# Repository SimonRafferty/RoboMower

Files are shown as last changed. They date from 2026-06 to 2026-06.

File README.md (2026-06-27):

# RoboMower - Autonomous RTK GPS Lawnmower
ESP32-S3 firmware for a home-built robot mower.  RTK GPS for positioning, VESC motor controllers over CANBUS, and a RadioMaster TX16S for manual driving & telemetry.

Why build one when you can buy a robot mower off the shelf?  The commercial ones either want a wire burying around the garden, or cost about the same as a small car - and none of them will cut a meadow.  This one is built like a small tank, cuts at whatever height you like and knows where it is to a couple of centimetres.
It's also an interesting project!

My intention with publishing this is so you can design your own mechanical hardware - any brushless drive and blade motors will work, controlled with VESCs. I'm using cheap knock-off 75100 types from AliExpress which seem to work great.

I'm going to publish the cad files for my mechanics but they might not be all that useful as the mower was mostly built out of bits I had laying around. you could do a much better job buying the 'right' parts.

in the settings (Web UI) I've tried to cover as many permutations of the layout of wheels, tracks etc as possible.

Watch the RoboMower mowing the lawn (https://www.youtube.com/watch?v=C5biq-wlkIc)

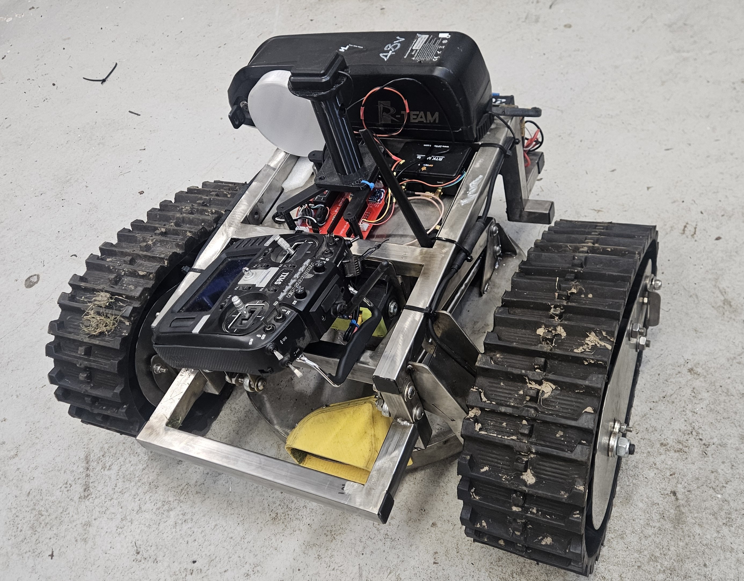
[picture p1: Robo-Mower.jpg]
The RoboMower - built like a small tank, because it basically is one


▶ I'm going to make a cover for the electronics which will make it look tidier! 

## How it works

You teach it the garden by driving it around the edge with the RC transmitter (or drawing the boundary on the map in the WebUI - both work).  That recorded line is the limit the mower's steering centre is allowed to reach, and it plans a path that covers everything inside it.

The path planning borrows the idea from a 3D printer slicer.  It follows the perimeter, then spirals inward ring by ring - each ring one cut-width inside the last - until it reaches the middle, so the whole lawn is covered in one continuous path.  If the garden pinches into separate areas (a neck through to a side lawn, say), each area gets its own spiral.

Position comes from a DFRobot RTK GPS (which was the most reasonably priced I could find).  The mower only trusts the GPS when it has a centimetre-accurate **RTK-Fixed** solution; the rest of the time it dead-reckons on wheel odometry.  That matters because gardens have trees, and RTK drops to a less accurate "Float" solution (sometimes a metre or two out) under the canopy - so rather than chase a bad fix, it coasts on odometry until a clean Fixed comes back.  Heading comes from a magnetometer-based 9-axis IMU (a Bosch BNO055): its on-chip fusion gives a tilt-compensated absolute compass heading, with a small offset trimmed from the GPS travel direction on straight RTK-Fixed runs.  The wheel-odometry scale (ticks per metre) and track width are self-calibrated against the GPS, again only on Fixed.

In case you're interested, you can find small tracks on eBay & AliExpress, intended for ATV's.  I used a pair of Bafung geared e-bike front wheel motors with the freewheel clutch welded up so they will drive in reverse to drive the tracks.  They produce bags of torque at low current and are super robust!

If it gets stuck in long wet grass, it raises the cutting deck, has another go, and progressively lowers it again.  If the blade is working too hard, it finishes the strip at maximum height and re-traces lower.  If it hits something (detected by the IMU - no bumpers), it notes the position as an obstacle and routes around it next time.

## Hardware

* ESP32-S3 DevKitC-1, the **N16R8** version (16MB Flash / 8MB PSRAM).  Be careful here - if you flash this firmware onto a generic S3 board with different memory, you'll likely brick it and need the Espressif Flash Download Tool or JTAG to recover it.  Ask me how I know.
* DFRobot GNSS-RTK board (Quectel LC29H) + NTRIP corrections.  Gives 1-2cm accuracy when it has an RTK Fixed solution.
* Bosch BNO055 9-axis IMU - on-chip sensor fusion gives an absolute heading; also used for tilt safety and collision detection.
* 3x VESC motor controllers on CANBUS at 250 kbit/s.  Mine are a mixed bag: two older HW4.x for the wheels (ID 1 & 2) and a HW6 for the blade (ID 3).  The older ones work fine, but make sure "Send CAN Status" is enabled in VESC Tool on ALL of them - the firmware needs the eRPM feedback, and the old boards default to silent.
* Blade motor is from a Gtech cordless mower (CLM021) - cheap, light and surprisingly tough.  The VESC limits it to 2800 RPM, so the firmware just asks for full speed and lets the VESC's current limit do the soft start.
* 13S battery, RadioMaster TX16S + ER8 receiver (ELRS), a linear actuator for cut height, and a PILZ safety relay as a proper hardware E-stop in the 48V line.  The ESP32 runs on a supercap backup so it doesn't lose its position when the PILZ fires or you swap the battery.

## Controls & monitoring

Day to day you don't need a laptop for anything.  The TX16S runs a Lua widget (in the repository) showing state, battery, blade load, GPS quality and a compass (with a line pointing at the next waypoint) - and it beeps at you when the mower wants attention.  CH4 selects Manual / Auto / Nudge, CH5 records the perimeter, CH6 arms the blade, CH7 pauses.

A few things make it pleasant to live with.  **Nudge** (CH4 up) hands the sticks back to you mid-mow without ending the run - shove it off an obstacle or correct a drift, flick back to Auto and it carries on exactly where it was.  Pausing and flicking back to Auto does the same as long as the mower hasn't been moved; if you carried it somewhere, it starts the cycle again.  And rather than swing a wide arc to reach a point behind it (which could wander over the boundary), it simply reverses to it.

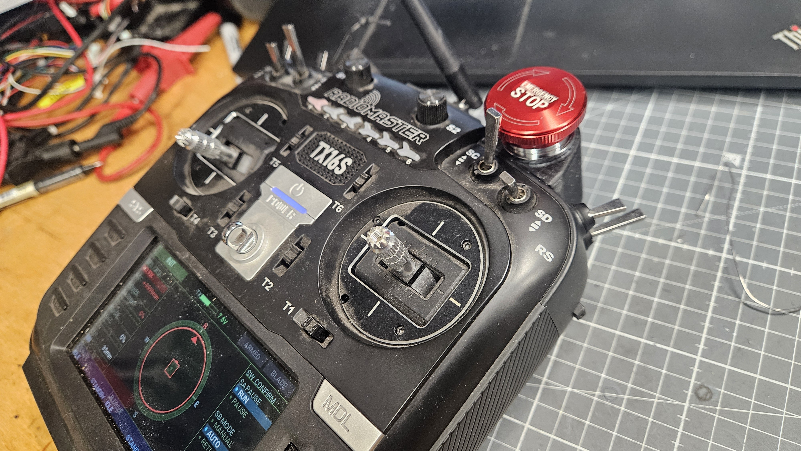
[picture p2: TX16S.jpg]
The TX16S running the Lua telemetry widget


*Everything at a glance on the transmitter - state, compass, GPS quality and blade load.  The big red button is exactly what it looks like.*

There's also a WebUI - a single HTML file that connects over Bluetooth from a phone (Chrome on Android).  That gives you a live map, perimeter editing, config settings and a diagnostics page with the raw VESC data.  If something misbehaves, the System Log on the dashboard tells you what the mower decided and why - copy & paste it if you want help.

When the battery gets low it warns you on the transmitter and the phone, then leaves the decision to you.  The VESCs look after themselves as the voltage drops, so there's no need for the firmware to panic on your behalf.

# Important Note:
If you use a different VESC for the blade, check which bytes of the CAN STATUS_5 message you're reading.  I had a bug where the firmware read the first two bytes (which are actually the tachometer) as the battery voltage.  It decoded as -0.1V, the firmware decided the battery was flat, and quietly refused to start the blade - while the transmitter cheerfully displayed "Armed & Running".  That one took a while to find.  The voltage is in bytes 4-5.
#

## Libraries & Dependencies

Built and tested against the versions below (the libraries are the **exact** versions used).  The firmware compiles on the **esp32 board core from 3.0.5 through the current 3.3.x** — newer cores moved the ESP32-S3 onto the NimBLE Bluetooth stack, and the code now handles both backends, so you don't need to pin an old core any more.  Install the core in **Boards Manager** and the libraries in **Library Manager** (Arduino IDE):

| Dependency | Version | What it's for |
|---|---|---|
| Arduino IDE | 2.x | (or arduino-cli 1.5.x) |
| **esp32** by Espressif (board core) | **3.0.5 – 3.3.x** | ESP32-S3 board support — and BLE, `Wire`, `Preferences`/NVS, LEDC (servo), TWAI (CAN) and FreeRTOS all ship with it.  Anything from 3.0.5 to the current 3.3.x builds; 3.0.5 is the most field-tested if you want to play it safe. |
| Adafruit BNO055 | 1.6.4 | the IMU |
| Adafruit Unified Sensor | 1.1.15 | dependency of the BNO055 library |
| Adafruit BusIO | 1.17.4 | dependency of the Adafruit libraries (Library Manager installs it for you) |
| FastLED | 3.10.3 | the status LED strip |
| DFRobot_RTK_LoRa | 1.0.0 | the RTK GPS board |

**Clipper2** (polygon offsetting for the spiral path planner) is **bundled in the repo** at `Robo-Mower-V2/src/clipper2/` — Arduino compiles the sketch's `src/` folder automatically, so there's nothing to install.

> **Getting `'esp_ble_gatts_cb_param_t' has not been declared`?**  That was an older version of this firmware, which only built on core 3.0.x.  **Pull the latest commit** — it now builds on 3.0.5 through the current 3.3.x.  (If you're stuck on an old firmware copy for some reason, installing **esp32 3.0.5** in Boards Manager and selecting it for this build also works.)

## Setting it up

1. Install the core + libraries from **Libraries & Dependencies** above.  Board "ESP32S3 Dev Module", Partition Scheme "Huge APP (3MB No OTA)", PSRAM "OPI PSRAM".
2. In VESC Tool: set CAN IDs 1 (left), 2 (right), 3 (blade), baud 250 kbit/s, enable CAN status messages on all three.  Drive motors in current control, blade in speed control with a 2800 RPM limit.
3. Wiring, calibration and the full operating procedure are in manual.md.  The CRSF telemetry format (if you want to build your own display) is in telemetry.md.
4. Drive the perimeter, press Auto, and watch it go.

Thanks to Benjamin Vedder for the VESC project - which makes projects like this possible, and to the OpenMower project for convincing me RTK GPS was the right approach.

I did consider just building the OpenMower project - but it's intended for a specific off the shelf mower rather than something mostly home built.  It would have taken extensive re-writing, so I decided to go it alone.  I also preferred to use an ESP32 rather than an RPi just because it boots near instantly.  I wasn't sure the whole thing would fit in an ESP32, but here it is!

Feel free to copy, share, change - whatever you like!

NOTE:
This is a DIY, experimental project.  It is not a turn-key product, and getting something wrong can put a heavy machine with a spinning blade somewhere you don't want it!  If you are not confident with electronics, software and/or mechanics - please walk away unless you're not fond of your fingers & toes!!!

I do not accept responsibility if it mows your flower beds, your neighbour's fence, the cat - or you!

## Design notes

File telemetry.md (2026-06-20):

# CRSF Telemetry Reference

ESP32-S3 → ER8 receiver → RadioMaster TX16S

## Overview

Five CRSF frame types are transmitted in a fixed rotation, one frame per
inter-packet gap (~2 ms silence between incoming RC frames at 100 Hz).
Data is snapshot at **2 Hz** by the state machine; frames are dispatched by
the CRSF receive task whenever a gap is detected.

**Rotation order:** FLIGHT_MODE → GPS → BATTERY → MOWER_STATUS → ATTITUDE → repeat

**Baud rate:** 420 000 (standard CRSF)

**Serial:** `Serial2` (ESP32-S3 UART2)

---

## Frame Format (all frames)

```
[sync] [len] [type] [payload ...] [CRC8]
```

| Byte | Description |
|---|---|
| `0xC8` | Sync byte (CRSF standard) |
| `len`  | `payload_len + 2` (counts type + CRC, excludes sync & len) |
| `type` | Frame type identifier |
| payload | Type-specific, see below |
| CRC8 | Polynomial `0xD5` (DVB-S2), computed over `type + payload` only |

---

## 1. FLIGHT_MODE — `0x1E`

Null-terminated ASCII string. Max 16 bytes (15 printable chars + `\0`).

**Payload (variable length, 2–16 bytes):**

| Offset | Type | Description |
|---|---|---|
| 0..N-1 | char[] | ASCII state name |
| N | `\0` | Null terminator (always present) |

**Possible values:**
`INIT`, `IDLE`, `MANUAL`, `LEARN`, `AUTO`, `RETRACE`, `BOG`, `OBS-AVOID`, `RETURN`, `PAUSED`, `MOT-OFF`

EdgeTX displays this natively on the main screen.

---

## 2. GPS — `0x02`

**Payload: 15 bytes, big-endian**

| Offset | Type | Unit | Description |
|---|---|---|---|
| 0–3 | int32 | degrees × 10⁷ | Latitude (WGS-84, EKF-fused) |
| 4–7 | int32 | degrees × 10⁷ | Longitude (WGS-84, EKF-fused) |
| 8–9 | uint16 | km/h × 100 | Ground speed (from EKF velocity × 3.6) |
| 10–11 | uint16 | degrees × 100 | Heading [0, 36000) |
| 12–13 | uint16 | metres + 1000 | Altitude (offset to stay unsigned; 0 m → 1000) |
| 14 | uint8 | count | Satellites used |

**Decoding in Lua:**
```lua
lat = payload_i32(0) / 1e7
lon = payload_i32(4) / 1e7
speed_kmh = payload_u16(8) / 100
heading_deg = payload_u16(10) / 100
alt_m = payload_u16(12) - 1000
sats = payload[14]
```

EdgeTX recognises this frame natively (GPS sensor).

---

## 3. BATTERY — `0x08`

**Payload: 8 bytes, big-endian**

| Offset | Type | Unit | Description |
|---|---|---|---|
| 0–1 | uint16 | V × 100 (centi-volts) | Battery voltage |
| 2–3 | uint16 | A × 100 (centi-amps) | Blade motor current |
| 4–6 | uint24 | mAh | Capacity used (3 bytes, MSB first) |
| 7 | uint8 | % | Battery remaining (0–100) |

**Battery:** 13S LiPo — full ≈ 54.6 V, low = 42.9 V (`BATTERY_LOW_V` in config.h)

**Decoding in Lua:**
```lua
voltage = payload_u16(0) / 100       -- volts
current = payload_u16(2) / 100       -- amps
cap_mah = (payload[4] << 16) | (payload[5] << 8) | payload[6]
remaining = payload[7]               -- percent
```

EdgeTX recognises this frame natively (battery sensor).

---

## 4. MOWER_STATUS — `0x80` (custom)

**Not an EdgeTX-standard frame.** Must be parsed by a Lua widget via
`crossfireTelemetryPop()`. Standard CRSF frame types (GPS, Battery, Attitude,
FlightMode) are consumed by EdgeTX internally and are **not** passed to Lua —
all data needed by the widget must be in this frame.

**Payload: 23 bytes** (15 before 2026-06-10, 19/20 before 2026-06-19, 22 before the beep-seq byte; the Lua widget accepts all — it length-guards each field)

| Offset | Type | Unit | Description |
|---|---|---|---|
| 0 | uint8 | enum | Robot state (see below) |
| 1 | uint8 | % | Headland progress (0–100) |
| 2 | uint8 | % | Strip progress (0–100) |
| 3 | uint8 | mm | Cut height |
| 4 | uint8 | % | Blade load (0–100) |
| 5 | uint8 | enum | GPS fix type (see below) |
| 6 | uint8 | bitfield | Status flags (see below) |
| 7–8 | uint16 | count | Obstacles detected (big-endian) |
| 9–10 | uint16 | cm | EKF position uncertainty (big-endian) |
| 11–14 | uint32 | dm² | Session mowed area (big-endian) |
| 15–16 | uint16 | V×100 | Battery voltage (big-endian) — duplicated here so the widget does not depend on the EdgeTX `RxBt` sensor |
| 17–18 | uint16 | deg×10 | Heading 0–359.9° (big-endian) — duplicated here so the widget does not depend on the EdgeTX `Yaw` sensor |
| 19 | uint8 | bitfield | BNO055 calibration: bits 7:6 sys, 5:4 gyro, 3:2 accel, 1:0 mag (each 0–3) |
| 20 | uint8 | enum | AUTO-start gate reason (0=OK/not gated; Lua banners it ~2 s) — see below |
| 21 | uint8 | deg/2 | Next-waypoint bearing, 0–179 = 0–358° (0=N, CW+), **255 = no waypoint**. Lua draws a yellow compass line |
| 22 | uint8 | counter | Beep sequence — incremented per `request_beep()`. Carried in every frame (not one-shot); the Lua plays the tone (type in flags bits 7:6) when this value advances, so a dropped frame can't lose a beep |

**AUTO-start gate reason (offset 20):**

| Value | Meaning |
|---|---|
| 0 | Not gated / OK |
| 1 | No perimeter taught |
| 2 | No GPS position (EKF unseeded) |
| 3 | Heading not GPS-established (drive a straight run) |
| 4 | GPS fix not RTK (need Float/Fixed) |
| 5 | EPE / Uncertainty too high |
| 6 | Mower outside perimeter |

**State values (offset 0):**

| Value | Name | Description |
|---|---|---|
| 0 | INIT | Boot / hardware init |
| 1 | IDLE | Armed, awaiting command |
| 2 | MANUAL | RC driving |
| 3 | LEARN | Recording perimeter |
| 4 | AUTO | Autonomous mowing |
| 5 | RETRACE | Overload recovery |
| 6 | BOG | Stall recovery |
| 7 | OBS-AVOID | Obstacle avoidance |
| 8 | NUDGE | AUTO held; operator drives via TX, then resumes |
| 9 | PAUSED | Mowing paused |
| 10 | MOT-OFF | Motors offline |

**Fix type values (offset 5):**

| Value | Meaning |
|---|---|
| 0 | No fix |
| 1 | GPS (autonomous) |
| 2 | DGPS |
| 4 | RTK fixed |
| 5 | RTK float |

**Flags bitfield (offset 6):**

| Bit | Meaning |
|-----|---|
| 0 | Armed |
| 1 | Blade on |
| 2 | Bog recovery active |
| 3 | Retrace active |
| 4 | RTK float (degraded) |
| 5 | Battery WARNING/LOW — Lua shows flashing battery banner (was "obstacle near", never implemented) |
| 7:6 | Beep request (2-bit field, see below) |

**Beep request (flags bits 7:6) — beep TYPE, carried in every frame (no longer one-shot):**

| Bits 7:6 | Value | Meaning |
|---|---|---|
| `00` | 0 | No beep |
| `01` | 1 | Confirm (short tone) |
| `10` | 2 | Warning (attention) |
| `11` | 3 | Fault (critical) |

The type alone is **not** an edge — pair it with the **beep sequence counter (byte 22)**. `request_beep()` bumps byte 22 per event; the Lua plays the tone of bits 7:6 only when byte 22 changes. This survives dropped frames (the next frame still carries the new sequence) and is handled in the widget's `background()` path so it beeps even when the widget isn't the focused screen — essential for per-corner LEARN confirmation.

**Decoding in Lua:**
```lua
local state_names = {
    [0]="INIT", [1]="IDLE", [2]="MANUAL", [3]="LEARN", [4]="AUTO",
    [5]="RETRACE", [6]="BOG", [7]="OBS-AVOID", [8]="RETURN",
    [9]="PAUSED", [10]="MOT-OFF"
}

state       = payload[0]
state_name  = state_names[state] or "?"
hprog       = payload[1]
sprog       = payload[2]
cut_mm      = payload[3]
blade_load  = payload[4]   -- 0–100 %; RPM-based since 2026-06-16 (Feature 2): 0 % at/above target rpm, 100 % at standstill
fix         = payload[5]
flags       = payload[6]
obs_count   = (payload[7] << 8) | payload[8]
ekf_unc_cm  = (payload[9] << 8) | payload[10]
mowed_dm2   = (payload[11] << 24) | (payload[12] << 16) | (payload[13] << 8) | payload[14]
mowed_m2    = mowed_dm2 / 100    -- convert dm² to m²

armed       = bit32.band(flags, 0x01) ~= 0
blade_on    = bit32.band(flags, 0x02) ~= 0
bog         = bit32.band(flags, 0x04) ~= 0
retrace     = bit32.band(flags, 0x08) ~= 0
rtk_float   = bit32.band(flags, 0x10) ~= 0
obs_near    = bit32.band(flags, 0x20) ~= 0
beep        = bit32.rshift(bit32.band(flags, 0xC0), 6)  -- 0=none 1=confirm 2=warn 3=fault
```

---

## 5. ATTITUDE — `0x14`

**Payload: 6 bytes, big-endian, signed**

| Offset | Type | Unit | Description |
|---|---|---|---|
| 0–1 | int16 | radians × 10000 | Pitch (always 0 — mower is flat) |
| 2–3 | int16 | radians × 10000 | Roll (always 0 — mower is flat) |
| 4–5 | int16 | radians × 10000 | Yaw (EKF heading, −π to +π) |

**Decoding in Lua:**
```lua
pitch_rad = payload_i16(0) / 10000
roll_rad  = payload_i16(2) / 10000
yaw_rad   = payload_i16(4) / 10000
heading_deg = math.deg(yaw_rad)    -- convert to degrees if needed
```

EdgeTX recognises this frame natively.

---

## CRC8 Implementation

Polynomial `0xD5` (DVB-S2). Input: `type` byte + all payload bytes. Sync and length bytes are excluded.

```lua
function crsf_crc8(data)
    local crc = 0
    for i = 1, #data do
        crc = bit32.bxor(crc, data:byte(i))
        for _ = 1, 8 do
            if bit32.band(crc, 0x80) ~= 0 then
                crc = bit32.bxor(bit32.lshift(crc, 1), 0xD5)
            else
                crc = bit32.lshift(crc, 1)
            end
            crc = bit32.band(crc, 0xFF)
        end
    end
    return crc
end
```

---

## Timing

- Data snapshot: updated at **2 Hz** (every 500 ms) from state machine
- Frame dispatch: one frame per CRSF inter-packet gap (~100 Hz opportunity)
- Rotation of 5 frames → each type sent ~20 times/sec (far exceeds 2 Hz data rate)
- Longest frame (GPS, 19 bytes total) takes ~360 µs at 420 kbaud — fits within the ~8 ms gap

---

## Source Files

| File | Purpose |
|---|---|
| `crsf_telemetry.h` | TelemetryData struct, public API |
| `crsf_telemetry.cpp` | Frame builders, CRC, rotation logic |
| `crsf_input.cpp` | CRSF receive + telemetry window detection |
| `state_machine.cpp` | Populates TelemetryData at 2 Hz |
| `config.h` | Battery voltage thresholds |

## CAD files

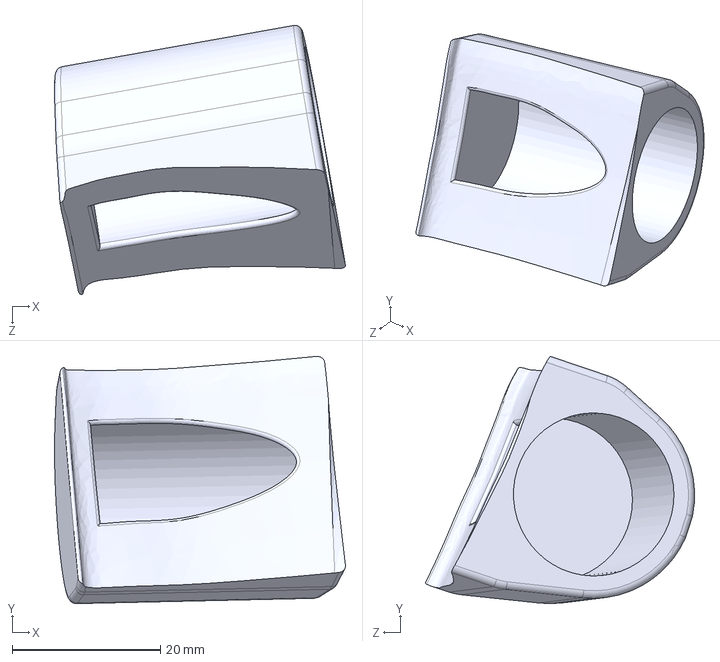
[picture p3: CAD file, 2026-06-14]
E-Stop Tx.STEP
39.3 x 33.4 x 36.3 mm

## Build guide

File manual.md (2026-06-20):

# RoboMower — User Manual

## Contents

1. [System Overview](#1-system-overview)
2. [RC Transmitter Layout](#2-rc-transmitter-layout)
3. [WebUI (Phone App)](#3-webui-phone-app)
4. [First Boot Checklist](#4-first-boot-checklist)
5. [Teaching the Perimeter](#5-teaching-the-perimeter)
6. [Starting a Mow](#6-starting-a-mow)
7. [Manual Driving](#7-manual-driving)
8. [Pause and Resume](#8-pause-and-resume)
9. [Emergency Stop](#9-emergency-stop)
10. [Cut Height](#10-cut-height)
11. [Battery](#11-battery)
12. [LED Status Reference](#12-led-status-reference)
13. [Configuration (WebUI)](#13-configuration-webui)
14. [Serial Debug Commands](#14-serial-debug-commands)
15. [Troubleshooting](#15-troubleshooting)

---

## 1. System Overview

RoboMower is a fully autonomous lawnmower controlled by an ESP32-S3 with RTK GPS positioning. It can be operated using a RadioMaster TX16S radio transmitter or a phone via Bluetooth (BLE).

**Key rule: RC transmitter and WebUI are mutually exclusive.** When the transmitter is switched on, the WebUI drive controls are locked out. Switch the transmitter off to use the phone.

**Hardware summary**

| Component | Role |
|---|---|
| ESP32-S3 DevKitC-1 (N16R8) | Main controller |
| Quectel LC29H + NTRIP | RTK GPS positioning (~5–10 cm accuracy) |
| RadioMaster TX16S + ER8 | RC control and telemetry |
| 3× VESCs (IDs 1, 2, 3) | Left drive, right drive, blade motor |
| PILZ safety relay | Hardware E-stop (cuts 48V bus) |
| 48V LiPo battery | Main power |
| Supercapacitor backup | Keeps ESP32 running for minutes after PILZ fires |

---

## 2. RC Transmitter Layout

All controls assume a RadioMaster TX16S in Mode 2 (throttle on the left stick). Assign switches as below — the exact physical switch is your choice as long as the channel numbers match.

| RC Channel | Function | Switch type | Position mapping |
|---|---|---|---|
| **CH1** | Steering | Left stick L/R | Left = turn left, Right = turn right |
| **CH2** | Throttle | Right stick U/D | Up = forward, Down = reverse |
| **CH3** | Cut height | Knob or slider | Low = minimum height, High = maximum height |
| **CH4** | Mode | 3-position switch | **Down** = MANUAL · **Centre** = AUTO · **Up** = NUDGE (hand sticks back, AUTO held) |
| **CH5** | Learn (perimeter record) | 2-position switch | Up (active) = recording on, Down = off |
| **CH6** | Arm (blade enable) | 2-position switch | Up = ARMED (blade allowed), Down = DISARMED |
| **CH7** | Pause / Soft E-stop | Momentary or latching button | Press/hold = pause all motion |
| **CH8** | Store point | Momentary button | One press = record current GPS position as a perimeter waypoint |

### CH4 Mode switch in detail

| CH4 position | State machine mode | What happens |
|---|---|---|
| Down | MANUAL | Operator drives with sticks; blade runs if CH6 armed |
| Centre | AUTO | Autonomous mowing (requires valid perimeter + GPS-established heading) |
| Up | NUDGE | AUTO is **held** — you drive the tracks with the sticks to nudge the mower (off an obstacle, or to correct a drift) **without ending the run**. Flip back to Centre and it resumes the mow exactly where it left off. The blade still follows CH6. (This replaced the old "return to start", which wasn't used.) |

> **Accidental mode switch:** if you flick AUTO → MANUAL by mistake and put it back to AUTO within ~4 seconds, it resumes the cycle where it left off rather than starting over. After 4 s, MANUAL → AUTO is treated as a fresh start.

### Telemetry on the TX16S

The mower transmits five CRSF telemetry frames back to the transmitter:
- **Flight mode** — shows current state name (INIT, IDLE, MANUAL, AUTO, etc.)
- **GPS** — position and speed (visible on EdgeTX GPS screen)
- **Battery** — voltage and estimated remaining %
- **Attitude** — heading
- **Mower Status (0x80)** — custom frame with mowing progress, blade load, fix quality, AUTO-deny reason, next-waypoint bearing, area mowed. Read with a Lua widget.

---

## 3. WebUI (Phone App)

The WebUI is a single HTML file (`robomower-pwa/robomower.html`). Open it in **Chrome on Android** — other browsers do not support Web Bluetooth.

> The phone controls only activate when the RC transmitter is **switched off** (failsafe active). A yellow banner at the top of the Controls tab says "RC Transmitter Active" and locks the buttons when the transmitter is on.

### Connecting

1. Open `robomower.html` in Chrome on Android.
2. Make sure the mower is powered on and the LED is showing a stable pattern (not INIT flashing).
3. Tap **Connect** in the top-right corner.
4. Select **RoboMower** from the Bluetooth device list.
5. The dot next to the Connect button turns green and shows **Connected**.

### Tabs

| Tab | Purpose |
|-----|---|
| **Dashboard** | Live status cards: state, GPS fix, battery, blade load, position uncertainty, session area. Also the Configuration panel (collapsed by default). |
| **Map** | Leaflet map showing the perimeter, planned mowing strips, GPS position, and coverage progress. Load/save/edit perimeter here. |
| **Controls** | All operational buttons: mode, arm, learn, drive sliders, cut height. |
| **Diagnostics** | Detailed real-time data from all sensors and subsystems. Only polls while the tab is open. |

### Controls tab — buttons

| Button | Function | Notes |
|---|---|---|
| **Manual** | Switch to MANUAL state | RC must be off |
| **Auto** | Switch to AUTO_MOWING state | Requires valid perimeter + GPS-established heading; mower must be inside it |
| **Learn** | Toggle perimeter learning on/off | See §5 |
| **Store Pt** | Record current GPS position as a waypoint | Only active during Learn mode |
| **Start Blade / Stop Blade** | Toggle blade arm | RC must be off. Only works in MANUAL or IDLE |
| **Pause / Resume** | Toggle BLE pause | Equivalent to pressing the CH7 button |

### Drive sliders

Two sliders replace the RC sticks when the transmitter is off:

- **Forward/Reverse slider** (left) — push up for forward, down for reverse. Returns to zero when released.
- **Left/Right slider** (right) — steer left or right. Returns to zero when released.

Sliders send commands continuously while held. The mower coasts to a stop within 2 seconds if the connection drops.

### Map tab — perimeter tools

| Button | Function |
|---|---|
| **Load from Mower** | Download the perimeter currently stored on the mower |
| **Send to Mower** | Upload the perimeter shown on the map to the mower |
| **Load File** | Load a perimeter JSON file from your phone |
| **Save File** | Save the current map perimeter as a JSON file |
| **Centre on GPS** | Pan the map to the mower's last known position |
| **Satellite** | Toggle between street map and satellite imagery |

You can draw and edit the perimeter directly on the map using the leaflet-geoman draw tools (pencil icon on the map). After editing, tap **Send to Mower** to upload it. Only the perimeter points are editable — the cut path and the GPS accuracy circles are display-only.

The map shows **two arrows**: a **red** one for the mower's fused (EKF) position and heading, and a **black** one for the raw GPS/RTK position and travel heading. When the fix is good they sit on top of each other; if the black one wanders off, that's the raw GPS being noisy (e.g. RTK "Float" under trees) and the red one is holding position on odometry — which is the intended behaviour. Each recorded perimeter corner also carries a small confidence circle sized to the GPS accuracy when it was taught.

---

## 4. First Boot Checklist

### Before power-on

- [ ] VESCs configured: CAN IDs set (Left=1, Right=2, Blade=3), baud 500 kbit/s, status broadcasts enabled. See README §6.
- [ ] NTRIP client running on a nearby device and corrections reaching the LC29H.
- [ ] 48V battery connected. PILZ relay in RUN state (green light).
- [ ] RC transmitter on, CH4 = MANUAL, CH6 = DISARMED, CH7 = not pressed.

### Power-on sequence

1. **Power on the ESP32** (supercapacitor supply or direct 5V).
2. The LED pulses **blue** slowly — this is the **INIT** state.
3. **Place the mower on flat ground and hold it completely still** for ~3 seconds while the gyro bias is collected. The LED shows blue throughout.
4. The mower waits for:
   - A valid RC signal (ER8 receiver linked to TX16S), AND
   - A GPS ENU origin (either loaded from NVS from a previous session, or the GPS must acquire a fix)
5. Once both are ready the LED changes to a slow **blue single blink** = **IDLE**.
6. On first use there is no stored origin. The GPS will auto-seed from the first RTK-quality fix. This may take 1–5 minutes if the NTRIP is slow to provide corrections.

---

## 5. Teaching the Perimeter

The perimeter defines the outermost boundary of the garden — the blade edge should follow this line exactly. Navigate the **blade edge** (not the chassis edge, not the antenna) along the desired outer cut line.

There are three ways to define the perimeter:

### Method A — Drive with RC (recommended for first setup)

1. CH4 = **MANUAL**, CH6 = **DISARMED**.
2. Flip **CH5** to active. The LED changes to fast green/amber flash = **LEARN**.
3. Drive slowly around the garden boundary. Points are recorded every 0.2 m of travel.
   - **Green fast flash** = RTK fixed (best accuracy ~2 cm)
   - **Amber fast flash** = RTK float (still good, ~5–15 cm)
4. When you return within 3 m of the start point the polygon closes automatically.
5. Flip **CH5** off to save. The LED flashes **white 3×** to confirm success, then returns to IDLE.

If the save fails (too few points, self-intersection, polygon too small), the LED returns to its previous pattern without the white flash. Check the serial output for the reason.

### Method B — Store individual points with RC + CH8

For precise corners or when driving continuously is difficult:

1. Enter LEARN mode as above (CH5 active).
2. Position the mower at each corner, then press the **CH8** momentary button to store that point. **The transmitter beeps once for each point recorded** — wait for the beep before moving on, so you don't double-record or miss a corner. Corners can be as little as 0.1 m apart.
3. When finished, flip CH5 off to close and save.

Each corner is tagged with the GPS accuracy at the moment you pressed CH8, so it's worth getting an **RTK-Fixed** solution (green LED) at each corner. A corner taught under tree cover in "Float" is automatically pulled slightly inward (toward the garden centre, by its uncertainty) so the mower keeps clear of the boundary there — the rest of the perimeter is unaffected.

### Method C — Draw on the WebUI map

1. Open the WebUI Map tab.
2. Use the draw tools to trace the perimeter directly on the satellite image.
3. Tap **Send to Mower** to upload. The mower derives the nav boundary and working area automatically.

You can also combine methods: record a rough perimeter by driving, tap **Load from Mower** in the WebUI, edit individual waypoints on the map to fix inaccurate sections, then **Send to Mower** again.

### After saving

The firmware automatically computes the **mowing plan**: a concentric inward spiral that follows the perimeter, then steps inward one cut-width per ring to the centre. If the garden pinches into separate areas, each is spiralled in turn. (A navigation boundary and working area are also derived and shown, but the spiral and the safety boundary work directly from the perimeter.)

The WebUI map shows the perimeter and the planned path after a successful upload or load.

---

## 6. Starting a Mow

### Via RC

1. Mower in **IDLE** state (blue single blink).
2. **Establish heading first.** The mower starts up with no absolute heading — it learns it from the GPS travel direction. Get an **RTK-Fixed** solution (green LED) and drive a short straight run in MANUAL; the TX compass swings to true North and then stays locked (you won't need to do it again unless you reset). AUTO will refuse to start until the heading is established (the TX banners the reason).
3. Set **CH4 = AUTO**.
4. Set **CH6 = ARMED** (blade on).
5. The mower enters AUTO_MOWING: LED = **orange double blink**.

The plan follows the perimeter, then spirals inward to the centre. If part of the garden is under tree cover and the fix drops to "Float", the mower keeps going on dead-reckoning (it does **not** chase the noisy Float position) and snaps back to GPS when a clean Fixed returns. To reach a node behind it (e.g. across a bridge between rings), it reverses rather than swinging a wide arc.

### Via WebUI

1. Turn off the RC transmitter (the "RC Transmitter Active" banner should disappear).
2. In the Controls tab, tap **Start Blade** to arm the blade.
3. Tap **Auto** to start mowing.

### During mowing

- **Orange double blink** = mowing, all well.
- **Yellow double blink** = RTK degraded to float — navigation continues on dead-reckoning until Fixed returns.
- The Dashboard shows progress (%), blade load, and EKF position uncertainty.
- The Map tab shows the planned route and which areas have been mowed, plus the red (EKF) and black (raw GPS) position arrows.

### Changing cut height mid-mow

- **RC**: Rotate the CH3 knob. The servo moves immediately; the new height is used for subsequent strips.
- **WebUI**: Drag the Cut Height slider in the Controls tab.

### Completion

When the spiral reaches the centre and the plan is finished, the mower stops, disarms the blade, and returns to **IDLE**. (There is no autonomous "drive back to start" — collect it from where it finishes, or drive it back in MANUAL.)

### Nudging mid-mow

If the mower needs a hand — too close to an obstacle, or a dead-reckoning drift to correct — flip **CH4 to UP (NUDGE)**. AUTO is held and you drive the tracks with the sticks. Flip back to **AUTO (Centre)** and it resumes the mow exactly where it left off (the plan and heading are preserved; the GPS keeps tracking your nudge, so it picks up correctly). The blade stays under CH6 throughout.

---

## 7. Manual Driving

### Via RC

1. CH4 = **MANUAL**. The LED turns solid **green**.
2. Drive with left stick (steering) and right stick (throttle).
3. CH6 = ARMED to run the blade. CH6 = DISARMED to stop it.

Heading stabilisation is active: if you drive straight without steering input, the mower holds its heading using the gyro.

### Via WebUI (RC must be off)

1. Ensure the transmitter is off.
2. In the Controls tab, tap **Manual**.
3. Use the Forward/Reverse and Left/Right sliders to drive.
4. Tap **Start Blade** to arm the blade if needed.

The sliders return to zero when released, bringing the mower to a gradual stop.

---

## 8. Pause and Resume

Pause can be triggered from any active state and holds everything in place — position, plan progress, and blade state are all preserved.

### Pausing

| Method | Action |
|---|---|
| RC CH7 button | Press/hold the pause button |
| Physical switch | Flip the GPIO6 latching switch on the chassis to GND |
| WebUI | Tap the **Pause** button in the Controls tab |

All three sources are OR'd: any one of them pauses the mower. To resume, all active sources must be cleared.

The LED shows **purple fast flash** while paused.

### Resuming — operator-initiated pause

1. Release the CH7 button, flip the GPIO6 switch open, or tap **Pause** again in the WebUI.
2. Set CH4 = AUTO (or tap **Auto** in WebUI).
3. The mower checks whether it **moved** while paused (it compares position before and after). If it didn't move, it **resumes from exactly where it stopped**. If it was carried somewhere (it moved significantly), it **restarts the cycle**, since its dead-reckoned position can no longer be trusted. The heading is kept either way — no need to re-establish it.

### Resuming — event-triggered pause

If the mower paused itself due to a safety event (perimeter breach, blade fault, tilt exceeded), an **event latch** is set and the mower will not resume automatically even when all pause inputs are cleared. This requires a deliberate acknowledgement:

1. **Activate the pause input** — press CH7 or tap **Pause** in the WebUI (pause goes active).
2. **Deactivate the pause input** — release CH7 or tap **Pause** again (pause goes inactive).
3. The latch clears on this falling edge and the serial output shows `Event latch cleared`.
4. Now set CH4 = AUTO or tap **Auto** to resume normally.

The LED pattern changes from fast flash back to slow flash once the latch is cleared, indicating it is now safe to resume.

---

## 9. Emergency Stop

### Hardware E-stop (PILZ)

The red mushroom button on the mower chassis cuts the 48V bus via the PILZ safety relay. This immediately and physically removes power from all three VESCs. The ESP32 continues running on the supercapacitor for several minutes.

- **Press the mushroom button** to cut power.
- The firmware detects VESC CAN silence and enters **STATE_MOTORS_OFFLINE**: LED = red/amber alternating.
- All session state is saved to NVS (position, waypoint index, cut height, mowed area).

**To recover:**
1. Check that the hazard has been resolved.
2. Unlock the PILZ button (twist or pull to release, depending on model).
3. The VESCs come back online. The ESP32 detects their CAN STATUS frames.
4. The firmware restores the saved session and offers to resume from the waypoint where it left off.
5. Set CH4 = AUTO (or tap **Auto**) to resume mowing.

> **The PILZ is hardware-only. There is no software command to trigger it.**

### Soft pause / stop via RC

The **CH7 pause button** is the recommended soft stop during normal operation:
- Press CH7 to pause immediately (drives and blade stop, position held).
- Release CH7 and set CH4 = AUTO to resume.

### What happens on RC failsafe (transmitter signal lost)

If the transmitter signal is lost for >500 ms while in MANUAL or LEARN mode:
- Drive motors stop immediately.
- State transitions to IDLE.
- The WebUI can take over if connected.

In AUTO_MOWING, RC failsafe causes an immediate stop only if the WebUI is also not connected (both control sources gone).

---

## 10. Cut Height

The cutting deck is raised and lowered by a servo. The range must be calibrated once (see §4 first boot).

**Height range:** 35 mm (min) to 90 mm (max) — adjust `cut_height_min_mm` and `cut_height_max_mm` in the WebUI Config panel if your deck has a different range.

| Method | How |
|---|-----|
| RC | Rotate the CH3 knob. The height changes continuously as you turn. Minimum change threshold is ~1 mm to filter noise. |
| WebUI | Drag the **Cut Height** slider in the Controls tab. Shows height in mm. |
| Serial | `CALHEIGHT TEST <mm>` (e.g. `CALHEIGHT TEST 50`) moves the servo to verify the height. |

During AUTO_MOWING, the firmware automatically raises the deck if bog recovery or retrace is triggered, and lowers it again step-by-step during recovery.

---

## 11. Battery

### Voltage monitoring

Battery voltage is read from the **blade VESC (CAN ID 3)** via STATUS_5 packets (bytes 4–5) — no external voltage divider hardware is needed. The pack is 13S LiPo (nominal 48 V).

| Voltage | State | Action |
|---|---|---|
| > 45.5 V | OK | Normal operation |
| 42.9–45.5 V | WARNING | Notification only: TX warning beep (repeats), flashing battery banner on the widget/phone, amber LED overlay. Mowing continues. |
| < 42.9 V | LOW | Notification only (as above, more urgent). The VESCs reduce power internally as the pack sags; **the decision to stop or finish the run is left to you.** |

There is deliberately **no** automatic blade lockout or drive-home on low battery — the VESCs manage the sagging voltage themselves, and a sudden autonomous stop/return mid-mow was more nuisance than help. Watch the warnings and bring it in when you're ready.

### Mid-session battery swap

The supercapacitor keeps the ESP32 running for several minutes after the PILZ fires. This allows a battery swap without losing the session:

1. Press the PILZ mushroom button (LED goes to red/amber alternating).
2. Swap the battery.
3. Restore the PILZ relay.
4. VESCs come back on — the ESP32 detects this and recovers the session automatically.
5. Set CH4 = AUTO to resume mowing.

---

## 12. LED Status Reference

Both the onboard NeoPixel (GPIO 48) and the external LED strip (GPIO 7) show the same colour and pattern.

| State | Colour | Pattern | Meaning |
|---|---|---|---|
| INIT | Blue | Slow pulse | Collecting gyro bias; waiting for RC + GPS |
| IDLE | Blue | Single blink (100ms on, 900ms off) | Ready, disarmed, no active task |
| MANUAL | Green | Solid | Operator driving |
| LEARN (RTK fixed) | Green | Fast flash (100ms on/off) | Recording perimeter — good accuracy |
| LEARN (RTK float/autonomous) | Amber | Fast flash | Recording perimeter — reduced accuracy |
| AUTO_MOWING (RTK fixed) | Orange | Double blink | Mowing, all well |
| AUTO_MOWING (RTK float) | Yellow | Double blink | Mowing, GPS slightly degraded |
| NUDGE | Cyan | Solid (with GPS overlay) | AUTO held; you're driving the tracks to nudge it |
| RETRACE | Yellow | Fast flash | Blade overloaded — retrace in progress |
| BOG_RECOVERY | Yellow | Slow pulse | Mower stalled/slipping — recovering |
| OBSTACLE_AVOID | Orange | Fast flash | IMU collision detected — avoiding |
| PAUSED | Purple | Fast flash | Mowing paused; waiting for resume |
| MOTORS_OFFLINE | Red/Amber | Alternating (500ms each) | PILZ fired or battery disconnected |
| Battery WARNING | Amber | Occasional flash (overlay) | Voltage below 45.5V; overlaid on current state |

**Quick guide:**
- **Orange double blink** = working normally — all is well
- **Purple fast flash** = paused; resume when ready
- **Yellow any pattern** = recoverable condition in progress; no immediate action needed
- **Red/Amber alternating** = PILZ fired; check hardware

---

## 13. Configuration (WebUI)

The Configuration panel is in the **Dashboard** tab (collapsed by default). Tap the header to expand. Configuration can only be changed when the mower is in **IDLE** or **MANUAL** state — the firmware rejects changes during mowing.

After editing, tap **Save Config** to send the new values. The firmware validates the inputs and sends back an error message if anything is out of range.

### Settings groups

**Drive control**

| Field | Default | Notes |
|---|---|---|
| Max duty | 0.60 | Duty cycle ceiling for both AUTO and MANUAL (0–1) |
| Max yaw rate | 0.8 rad/s | Steering rate at full stick deflection |
| Heading Kp / Kd | 0.30 / 0.05 | Gyro heading stabilisation gains |
| Manual max speed | 0.5 m/s | Maximum speed at full throttle in MANUAL |
| Min turn radius | 0.0 m | 0 = tracked vehicle (can pivot on spot) |

**Robot footprint** (from steering centre)

Measure from the midpoint of the front axle:

| Field | Default | Measure |
|---|---|---|
| Front | 0.50 m | Steering centre → front chassis edge |
| Rear | 0.20 m | Steering centre → rear chassis edge |
| Left | 0.30 m | Steering centre → left chassis edge |
| Right | 0.30 m | Steering centre → right chassis edge |

> Getting these wrong affects safety. If Left/Right are too small, the chassis may overhang the perimeter.

**Chassis / drive**

| Field | Notes |
|---|---|
| Chassis width | Distance between driven wheel contact patches (= track width) |
| Chassis length | Wheelbase front to rear |
| Wheel radius | Radius of driven wheels — must be measured precisely for odometry |
| Motor pole pairs | Rotor magnetic pole PAIRS (not total poles). Default: 7 |
| Gear ratio | Gearbox reduction from motor shaft to wheel. Default: 20:1 |

**GPS antenna offset**

Offset of the RTK antenna from the steering centre. Positive forward = antenna is ahead of the axle.

| Field | Default |
|---|---|
| Forward offset | −0.20 m (antenna behind axle) |
| Right offset | 0.00 m (centred) |

**Cutting geometry**

| Field | Default | Notes |
|---|---|---|
| Steer to cut | 0.0 m | Signed distance: steering centre → blade disc centre |
| Blade radius | 0.21 m | Radius of cutting disc |
| Cut width | 0.38 m | Effective cut width per pass |
| Strip overlap | 0.02 m | Overlap between adjacent spiral rings (must be < cut width); ring spacing = cut width − overlap |
| Blade pole pairs | 10 | Blade motor pole pairs — measured from rotor detents |
| Blade RPM | 2800 | Target blade mechanical RPM |

**Cut height limits**

| Field | Default |
|---|---|
| Min mm | 35 mm |
| Max mm | 90 mm |

**Path following**

| Field | Default | Notes |
|---|---|---|
| Lookahead base | 0.40 m | Minimum lookahead distance at zero speed |
| Lookahead K | 0.80 s | Lookahead scales with speed: total = base + K × speed |
| Mow speed | 0.15 m/s | Forward speed while mowing |
| Headland speed | 0.20 m/s | Speed during perimeter passes |
| Transit speed | 0.30 m/s | Speed when not mowing (repositioning) |

---

## 14. Serial Debug Commands

Connect via USB at **115200 baud**. The mower outputs 2 Hz JSON telemetry automatically.

| Command | Description |
|---|---|
| `STATUS` | Full state: pose, heading, fix quality, speed, progress, blade load, calibration |
| `PERIMETER` | Dump recorded perimeter polygon vertices |
| `NAVBOUNDARY` | Dump navigation boundary polygon |
| `WORKINGAREA` | Dump working area polygon |
| `PLAN` | Dump the current waypoint plan |
| `GRID` | ASCII map of headland coverage progress |
| `UNREACHABLE` | List zones too narrow for the robot to enter |
| `EKFSTATE` | Full EKF state vector and 4×4 covariance matrix |
| `CALDUMP` | Gyro bias, blade calibration current, servo calibration |
| `OBSTACLES` | All tracked obstacle positions with retry count |
| `ERRORS` | Last 20 software-triggered pause events (perimeter breach, blade fault, etc.) |
| `CLEARPERIM CONFIRM` | Erase the stored perimeter from NVS (requires the word CONFIRM) |
| `RESETEKF` | Reset EKF covariance matrix (does not reset position) |
| `CALHEIGHT TEST <mm>` | Move servo to a specific height for verification |
| `PAUSE` | Toggle pause when connected to serial (same as CH7) |

### Automatic 2 Hz JSON telemetry

```json
{"t":123456,"state":"AUTO","x":3.21,"y":7.84,"hdg":1.57,
 "fix":4,"sat":12,"vel":0.43,"hprog":0.42,"sprog":0.71,
 "cutH":35,"bog":0,"obs":2,"unc":0.04,
 "bladeRPM":2795,"bladeA":8.3,"bladeLoad":0.69,"cutStatus":"NORMAL",
 "battV":50.4,"battState":"OK","collBase":0.082}
```

---

## 15. Troubleshooting

### Mower stays in INIT

- Check that the ER8 receiver is linked to the TX16S and the transmitter is on.
- Check that the GPS module has a clear sky view. INIT waits for a GPS ENU origin.
- On first use the origin is auto-seeded from the first RTK-quality fix. This can take several minutes if the NTRIP connection is slow or there is little sky visibility.
- Check USB serial output for `[BOOT]` messages.

### LED shows red/amber alternating immediately

The PILZ has fired or the VESCs lost power before the CAN bus was established. Check:
- Is the PILZ relay in RUN state?
- Are the VESCs powered from the 48V battery?
- Are the CAN bus wires connected and terminated at both ends?

### AUTO won't start (nothing happens when CH4 = AUTO)

AUTO is gated and the TX banner shows the reason for ~2 seconds. Common ones:
- **Heading not set** — drive a short straight run with an RTK-Fixed solution so the heading establishes (the TX compass swings to North), then try again.
- **GPS fix not RTK** — wait for at least a Float (preferably Fixed) solution.
- **Outside perimeter** — the mower's position is outside the recorded boundary.
- **No perimeter** — teach one first (§5).

### Mower enters PAUSED immediately after starting AUTO

The safety perimeter breach check triggered on entry. Possible causes:
- The mower is physically outside the recorded perimeter boundary.
- The GPS position is inaccurate (large EKF uncertainty) and the computed position appears outside the nav boundary.
- The perimeter was drawn/recorded in a different GPS session and the ENU origin has shifted.

Check `EKFSTATE` for position uncertainty and `STATUS` for GPS fix quality.

### WebUI "RC Transmitter Active" banner will not clear

The transmitter is on or the CRSF receiver is still linked. Power off the TX16S completely — switching to failsafe channel positions is not enough. The firmware detects the active link, not just the channel positions.

### Mower won't start blade in AUTO (blade not spinning)

- CH6 must be in the ARMED position (or **Start Blade** tapped in WebUI).
- Check `STATUS` output: `armed: true` must appear.
- The blade ramps up over ~2 seconds (the VESC's current limit does the soft start) — give it a moment.

### Recovery modes (BOG / RETRACE / obstacle-avoid)

These are built but **currently disabled** — the detectors produced too many false triggers, so for now the blade is operator-controlled (CH6) in AUTO and the only automatic responses left are tilt and the perimeter-breach/VESC-silence safeties. So you should not see BOG_RECOVERY, RETRACE or OBSTACLE_AVOID in normal use; they'll be re-enabled once the detectors are trustworthy.

### GPS position jumps during mowing

The mower only snaps its position to the GPS when it has a clean **RTK-Fixed** solution; on Float (e.g. under trees) it ignores the noisy fix and dead-reckons on odometry, so the on-map position should stay smooth and only correct when Fixed returns. Watch the two map arrows: if the **black** (raw GPS) arrow jumps about while the **red** (fused) one holds steady, that's working as intended. If the *red* arrow drifts a long way before a Fixed pulls it back, you spent a long stretch in Float — improving sky view / antenna gain (more Fixed) is the fix.

### Perimeter save fails after driving

Common reasons (check serial output):
- **Fewer than 6 points**: drove too fast — slow down or use CH8 to store individual points.
- **Self-intersecting polygon**: the driven path crossed itself. Start again or edit in the WebUI.
- **Area less than 5 m²**: the perimeter is too small.
- **No viable robot fit**: after insetting the navigation boundary, nothing remains — garden is too narrow for the robot.

### Blade warning (load high / not reaching RPM)

In AUTO the blade is operator-controlled and a blade fault **warns but does not pause** the mower (it keeps driving). If the blade load reads high or it isn't reaching target RPM:
- Object lodged in the cutting deck — inspect and clear.
- Blade belt/spindle failure.
- Blade VESC fault — check VESC Tool for motor faults.

(The event-latched PAUSE still applies to the *active* safeties: perimeter breach and tilt.)

After clearing the cause, cycle the CH7 pause button to acknowledge and resume.

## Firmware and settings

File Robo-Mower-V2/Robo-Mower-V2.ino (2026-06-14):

// ══════════════════════════════════════════════════════════════════════════════
//  Robo-Mower-V2.ino — RoboMower ESP32-S3 Firmware v3
//  Arduino entry point: setup() and loop() only.
//  All subsystem logic is in the accompanying .cpp / .h files.
//
//  See README.md for full setup, calibration, and serial command reference.
// ══════════════════════════════════════════════════════════════════════════════
//
//  ── BOARD ──────────────────────────────────────────────────────────────────
//
//  Board:            ESP32S3 Dev Module
//                    (Espressif ESP32-S3-WROOM-1, N16R8 — 16MB flash, 8MB OPI PSRAM)
//  Arduino core:     esp32 by Espressif Systems v3.x
//  Partition scheme: Huge APP (3MB No OTA / 1MB SPIFFS)  ← REQUIRED
//                    Firmware exceeds the default 1.2MB partition.
//  PSRAM:            OPI PSRAM  (required for N16R8; set to Disabled if no PSRAM)
//  USB Mode:         Hardware CDC and JTAG
//  Upload speed:     921600 (default)
//  CLI FQBN:         esp32:esp32:esp32s3
//
//  ── REQUIRED LIBRARIES (install via Library Manager) ──────────────────────
//
//  Adafruit BNO055                   Adafruit                IMU (I2C, 100Hz)
//  Adafruit Unified Sensor           Adafruit                (BNO055 dependency)
//  FastLED                           Daniel Garcia          WS2812 LED control
//
//  ── BUILT-IN (ESP32 Arduino core — do NOT install separately) ─────────────
//
//  driver/twai.h          CAN/TWAI peripheral (VESC communication)
//  Preferences.h          NVS key-value storage (calibration, session state)
//  nvs.h / nvs_flash.h    NVS blob storage (perimeter, obstacle map)
//  HardwareSerial         UART1 = GPS, UART2 = CRSF RC receiver
//
//  ── COMPILE-TIME OPTIONS (config.h) ───────────────────────────────────────
//
//  TEST_MODE   0   Normal operation.
//              1   Runs geometry unit tests from setup() then halts.
//                  Use to verify geometry routines after any planner change.
//
//  ── PIN CONNECTIONS ────────────────────────────────────────────────────────
//
//  GPIO  1   TWAI RX   ←  SN65HVD230 RXD pin
//              CAN transceiver shared by all 3 VESCs (250 kbit/s, CAN_BAUD_RATE)
//              Twisted-pair CANH/CANL, 120Ω termination at each end of bus
//
//  GPIO  2   TWAI TX   →  SN65HVD230 TXD pin
//
//  GPIO  4   (unused)  —  formerly battery ADC voltage divider
//              Battery voltage now read from VESC CAN STATUS_5 (no hardware needed)
//
//  GPIO  5   LEDC PWM  →  Cut-height servo signal wire
//              50 Hz, 1000–2000 µs pulse width, LEDC channel 0
//              Servo power: 5V rail; signal logic: 3.3V (direct connection OK)
//
//  GPIO  6   Pause switch  ←  Latching switch to GND (SPST)
//              INPUT_PULLUP, active LOW, 50ms settle debounce
//              Switch CLOSED (GND) → pause AUTO_MOWING, all state preserved
//              Switch OPEN         → resume mowing from same position
//              CH7 on RC transmitter provides independent pause (either input pauses)
//
//  GPIO  7   WS2812 data  →  External LED strip data-in
//              FastLED, SK6812/WS2812B, 8 LEDs (LED_EXTERNAL_COUNT)
//              Power: 5V rail; data: 3.3V logic (direct connection OK for most strips)
//
//  GPIO  8   I2C SDA   ↔  Adafruit BNO055 SDA pin
//              Wire.h, 100 kHz (BNO055 clock-stretch quirk); 4.7kΩ pull-up to 3.3V on each line
//
//  GPIO  9   I2C SCL   →  Adafruit BNO055 SCL pin
//
//              BNO055 wiring summary:
//                ESP32 3.3V  →  VIN
//                ESP32 GND   →  GND   (ADR low/unconnected → I2C address 0x28)
//
//  GPIO 10   Serial1 RX  ←  Quectel LC29H RTK GPS module TX pin
//              115200 baud, NMEA 0183 ($GNGGA sentences)
//              LC29H supply: check module board (typically 3.3V or 5V)
//              RTK corrections supplied externally via NTRIP (not this firmware)
//
//  GPIO 14   Serial1 TX  →  Quectel LC29H RTK GPS module RX pin
//              115200 baud, data requests (DFRobot RTK LoRa library)
//
//  GPIO 11   Serial2 RX  ←  RadioMaster ER8 CRSF receiver TX pin
//              420000 baud, CRSF protocol, RC channels inbound
//
//  GPIO 12   Serial2 TX  →  RadioMaster ER8 CRSF receiver RX pin
//              420000 baud, CRSF telemetry uplink (GPS position, battery,
//              attitude, custom mower status frame 0x80)
//
//              ER8 wiring summary:
//                5V rail  →  ER8 power (receiver requires 5V)
//                ESP32 GND  →  ER8 GND
//
//  GPIO 48   WS2812 data  →  Onboard NeoPixel (DevKitC-1 fixed location)
//              FastLED, single LED, mirrors external strip pattern
//              No external wiring needed
//
//  ── CAN BUS — VESC MOTOR CONTROLLERS ──────────────────────────────────────
//
//  All three VESCs share one CAN bus (daisy-chain, 120Ω at each end):
//
//  CAN ID 1  Left drive VESC    Differential drive, left wheel
//  CAN ID 2  Right drive VESC   Differential drive, right wheel
//  CAN ID 3  Blade VESC         Gtech CLM021 cutting deck (800W / 48V)
//
//  The blade VESC (ID 3) must have STATUS_5 (CAN packet ID 27) enabled
//  in VESC Tool — this is the source of battery voltage telemetry
//  (changed 2026-06-07 from the left drive VESC, which on HW v4 may not
//  broadcast STATUS_5).
//  See README.md §VESC Tool Configuration for required settings.
//
//  ── POWER RAILS ────────────────────────────────────────────────────────────
//
//  48V battery  →  PILZ safety relay  →  all three VESCs
//  5V rail      →  ESP32-S3 DevKitC-1 (USB or 5V pin), ER8 receiver,
//                  cut-height servo power
//  3.3V (ESP32 internal LDO)  →  BNO055, SN65HVD230, LED data lines
//
//  Supercapacitor backup (separate supply):
//    Powers ESP32 + ER8 + RTK GPS for several minutes after PILZ fires.
//    Enables clean NVS save and battery-swap mid-session without losing position.
//
//  PILZ safety relay: hardware E-stop only — no ESP32 GPIO connection.
//  When PILZ fires, VESCs go silent on CAN → firmware enters STATE_MOTORS_OFFLINE.
//
// ══════════════════════════════════════════════════════════════════════════════

// ── System includes ──────────────────────────────────────────
#include <Arduino.h>
#include <Wire.h>
#include <Preferences.h>
#include <nvs.h>
#include <nvs_flash.h>
#include <driver/twai.h>
#include <FastLED.h>
#include <vector>
#include <algorithm>
#include <cmath>

// Adafruit BNO055 library (install via Library Manager)
#include <Adafruit_BNO055.h>

// ── Local module includes (in dependency order) ──────────────
#include "config.h"
#include "mower_config.h"
#include "geometry.h"
#include "geometry_test.h"
#include "nvs_storage.h"
#include "crsf_input.h"
#include "crsf_telemetry.h"
#include "vesc_can.h"
#include "rtk_gps.h"
#include "imu.h"
#include "collision_detect.h"
#include "servo_output.h"
#include "obstacle_map.h"
#include "ekf_localiser.h"
#include "perimeter.h"
#include "cutting_monitor.h"
#include "coverage_planner.h"
#include "node_follower.h"
#include "odo_calib.h"
#include "bog_recovery.h"
#include "retrace.h"
#include "battery_monitor.h"
#include "safety.h"
#include "state_machine.h"
#include "ble_server.h"
#include "sys_log.h"

// ─────────────────────────────────────────────────────────────

void setup() {
    DBG_BEGIN(115200);
    delay(500);  // Allow USB CDC to connect
    DBG_PRINTLN("[BOOT] RoboMower v3 starting...");

#if TEST_MODE
    // ── TEST MODE: run geometry unit tests and halt ──────────
    DBG_PRINTLN("[TEST] Running geometry unit tests...");
    int failures = geometry_test_runAll();
    DBG_PRINTF("[TEST] Done: %d failures\n", failures);
    DBG_PRINTLN("[TEST] Halting. Reflash without TEST_MODE for normal operation.");
    while (true) { delay(1000); }
#endif

    // ── Normal boot sequence ─────────────────────────────────

    // 1. NVS storage (must be first — validates all blobs)
    if (!nvs_storage_init()) {
        sys_log_push("NVS: one or more stored blobs failed CRC — data may be corrupt");
    }

    // 1b. Runtime mower config (after NVS, before any module that uses dimensions)
    mower_config_init();

    // 1c. Odometry self-calibration (after mower_config — needs nominal track/wheel)
    odo_calib_init();

    // 2. Hardware peripherals
    pinMode(PAUSE_PIN, INPUT_PULLUP);   // physical pause switch, GPIO6, active LOW
    servo_output_init();
    vesc_can_init(CAN_TX_PIN, CAN_RX_PIN);  // from config.h
    if (!imu_init()) {
        sys_log_push("IMU: BNO055 not detected — check I2C wiring");
    }
    collisionDetectInit();     // loads collision baseline from NVS
    rtk_gps_init();            // starts GPS parse task on Core 0
    // Telemetry MUST init before the CRSF RX task starts: the task calls
    // crsf_telemetry_service() on the first inter-packet gap (within ~3 ms of
    // creation, at priority 14 — preempting the rest of setup() on this core),
    // and that uses the mutex crsf_telemetry_init() creates. Starting the task
    // first races a null-mutex xSemaphoreTake → configASSERT abort at boot.
    crsf_telemetry_init();
    crsf_input_init();         // starts CRSF RX task on Core 1

    // 3. Algorithm modules
    ekf_init();
    perimeter_init();          // loads from NVS

    // The perimeter origin (first vertex lat/lon) is stored in NVS alongside
    // the perimeter and restored in rtk_gps_init(). Both are set atomically
    // by handle_send_perimeter(), so no separate consistency check is needed.

    obstacle_map_init(perimeter_get_perimeter());  // init grid
    coverage_planner_init();
    node_follower_init();
    cutting_monitor_init();

    // 4. Battery monitor (before safety — safety checks battery state)
    battery_monitor_init();    // configures ADC, loads NVS cal offset

    // 5. Safety (must start before state machine)
    safety_init();             // starts safety watchdog task on Core 1

    // 6. State machine (starts from INIT state)
    state_machine_init();

    // 7. BLE GATT server (after state machine so getters are valid)
    ble_server_init();

    DBG_PRINTLN("[BOOT] Setup complete.");
}

void loop() {
    // Core 1 main loop — runs state machine at 10Hz
    static uint32_t last_sm_ms = 0;
    uint32_t now = millis();

    if (now - last_sm_ms >= 100) {  // 10Hz
        last_sm_ms = now;
        state_machine_update();
    }

    // Handle serial commands (non-blocking check)
    static char serial_buf[64];
    static int  serial_idx = 0;
    while (DBG_AVAILABLE()) {
        char c = DBG_READ();
        if (c == '\n' || c == '\r') {
            if (serial_idx > 0) {
                serial_buf[serial_idx] = '\0';
                state_machine_handle_serial(serial_buf);
                serial_idx = 0;
            }
        } else if (serial_idx < 63) {
            serial_buf[serial_idx++] = c;
        }
    }

    // Yield to avoid starving Core 1 tasks
    vTaskDelay(1);
}

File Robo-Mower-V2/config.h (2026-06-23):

#pragma once
#include <Arduino.h>
#include <cmath>

// ══════════════════════════════════════════════════════════════════════════════
//  config.h — RoboMower ESP32-S3 Firmware
//  All pin definitions, physical constants, timing, EKF tuning, derived values.
//  NO implementation logic in this file — only #define constants.
//
//  Source references:
//    Spec: Robo_Mower_claudecode_prompt_v3.md
//    Assumptions: ASSUMPTIONS.md (A02, A03, A05, A23)
//    Pins: ARCHITECTURE.md Section 3
//    Decisions: HANDOFFS/01_architecture/HANDOFF.md
// ══════════════════════════════════════════════════════════════════════════════


// ══════════════════════════════════════════════════════════════════════════════
//  BUILD FLAGS
// ══════════════════════════════════════════════════════════════════════════════

// TEST_MODE: when 1, run geometry_test suite from setup() and halt.
//            Compile as normal (0) for production firmware.
#define TEST_MODE                    0

// DEBUG_SERIAL: when 1, enable USB Serial debug output (bench testing).
//               when 0, all Serial output compiles to no-ops (production / field).
//               Does NOT affect Serial2 (CRSF) or BLE telemetry.
// KEEP THIS 0. There is NO USB serial access while the mower is operating, so
// serial debug cannot validate field behaviour. Route all runtime diagnostics to
// the PWA log via sys_log_push() (surfaced in the STATUS JSON `log` array and the
// PWA Diagnostics tab) instead of Serial.
#define DEBUG_SERIAL                 0

// BENCH_TEST_NO_VESC: set to 1 ONLY when testing on bench without VESCs connected.
// Suppresses cutting-monitor state transitions (blade fault / overload / stall).
// Never set this to 1 in field firmware.
#define BENCH_TEST_NO_VESC           0

#if DEBUG_SERIAL
  #define DBG_BEGIN(baud)   do { Serial.begin(baud); } while(0)
  #define DBG_PRINTF(...)   Serial.printf(__VA_ARGS__)
  #define DBG_PRINTLN(...)  Serial.println(__VA_ARGS__)
  #define DBG_PRINT(...)    Serial.print(__VA_ARGS__)
  #define DBG_AVAILABLE()   Serial.available()
  #define DBG_READ()        Serial.read()
#else
  #define DBG_BEGIN(baud)   ((void)0)
  #define DBG_PRINTF(...)   ((void)0)
  #define DBG_PRINTLN(...)  ((void)0)
  #define DBG_PRINT(...)    ((void)0)
  #define DBG_AVAILABLE()   (0)
  #define DBG_READ()        (-1)
#endif

// HEADLAND_FIRST: always 1 — headland passes are mowed before working-area strips.
//   The HEADLAND_FIRST=0 code path is not implemented (different vehicle topology).
#define HEADLAND_FIRST               1


// ══════════════════════════════════════════════════════════════════════════════
//  GPIO PIN ASSIGNMENTS  (from ARCHITECTURE.md Section 3)
//  ESP32-S3 DevKitC-1 N16R8
//  Avoided: GPIO0/3/45/46 (strapping), GPIO19/20 (USB), GPIO35/36/37 (PSRAM)
// ══════════════════════════════════════════════════════════════════════════════

// ── CAN / TWAI (VESC motor controllers) ──────────────────────────────────────
#define CAN_TX_PIN                   2   // TWAI TX → CAN transceiver TXD pin
#define CAN_RX_PIN                   1   // TWAI RX ← CAN transceiver RXD pin
// Note: GPIO1 and GPIO2 are swapped vs. PCB silkscreen — the board routes
// GPIO1 to the module's RXD and GPIO2 to the module's TXD.

// ── Servo (cut height) ───────────────────────────────────────────────────────
#define SERVO_PIN                    5   // LEDC channel 0, 50Hz PWM, 1000–2000μs

// ── Physical pause switch ────────────────────────────────────────────────────
#define PAUSE_PIN                    6   // INPUT_PULLUP, active LOW, latching switch to GND
                                         // Closed (GND) = pause AUTO_MOWING
                                         // Open  (HIGH) = resume AUTO_MOWING
#define PAUSE_DEBOUNCE_MS           50   // settle time (ms) before level change is acted on

// ── External LED strip ───────────────────────────────────────────────────────
// NOTE: changed from spec default (GPIO10) to GPIO7 — GPIO10 is used for GPS Serial1 RX.
//       See HANDOFFS/01_architecture/HANDOFF.md for rationale.
#define LED_EXTERNAL_PIN             7   // WS2812/SK6812 data line (FastLED)

// ── IMU I2C (BNO055) ─────────────────────────────────────────────────────────
#define IMU_SDA_PIN                  8   // Wire I2C SDA — ESP32-S3 Arduino default
#define IMU_SCL_PIN                  9   // Wire I2C SCL — ESP32-S3 Arduino default, 400kHz

// ── GPS UART (DFRobot RTK LoRa) — bidirectional (request/response protocol) ──
#define GPS_RX_PIN                  10   // Serial1 RX ← GPS module TX
#define GPS_TX_PIN                  14   // Serial1 TX → GPS module RX (sends data requests)

// ── CRSF UART (RadioMaster ER8) ──────────────────────────────────────────────
#define CRSF_RX_PIN                 11   // Serial2 RX ← ER8 TX, 420000 baud
#define CRSF_TX_PIN                 12   // Serial2 TX → ER8 RX, telemetry uplink
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

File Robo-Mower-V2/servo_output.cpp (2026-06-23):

// ══════════════════════════════════════════════════════════════════════════════
//  servo_output.cpp — RoboMower ESP32-S3 Firmware
//  Cut-height servo controller using ESP32 LEDC peripheral.
//
//  The servo is mechanically calibrated: 1000 µs = minimum deck height,
//  2000 µs = maximum deck height.  No software calibration is required.
//
//  Uses the ESP-IDF LEDC API directly (not the Arduino ledcAttach wrappers)
//  to guarantee permanent ownership of Timer 1 / Channel 1.
//  14-bit resolution @ 50 Hz: duty = (pulse_µs × 16383) / 20000.
// ══════════════════════════════════════════════════════════════════════════════

#include "servo_output.h"
#include "config.h"
#include "mower_config.h"
#include <driver/ledc.h>

// ── ESP-IDF LEDC resource assignments ────────────────────────────────────────
#define SERVO_LEDC_SPEED    LEDC_LOW_SPEED_MODE
#define SERVO_LEDC_TIMER    LEDC_TIMER_1
#define SERVO_LEDC_CH       LEDC_CHANNEL_1

// ── Fixed pulse range (mechanically calibrated) ───────────────────────────────
#define SERVO_MIN_US  1000  // minimum deck height
#define SERVO_MAX_US  2000  // maximum deck height

// ── Module state ─────────────────────────────────────────────────────────────
static uint16_t servo_current_pulse_us = 0;
static uint32_t s_servo_last_drive_ms  = 0;     // millis() of last commanded movement
static bool     s_servo_idle           = false; // true = PPM stopped (actuator de-powered)

// ── Helpers ──────────────────────────────────────────────────────────────────

static inline float clampf(float v, float lo, float hi)
{
    if (v < lo) return lo;
    if (v > hi) return hi;
    return v;
}

#define SERVO_DUTY_MAX  ((1UL << SERVO_LEDC_RES_BITS) - 1UL)   // 16383

static inline uint32_t pulseUsToDuty(uint16_t pulse_us)
{
    return ((uint32_t)pulse_us * SERVO_DUTY_MAX) / 20000UL;
}

static void ledcWritePulse(uint16_t pulse_us)
{
    DBG_PRINTF("[SERVO] pulse=%d us\n", (int)pulse_us);
    ledc_set_duty(SERVO_LEDC_SPEED, SERVO_LEDC_CH, pulseUsToDuty(pulse_us));
    ledc_update_duty(SERVO_LEDC_SPEED, SERVO_LEDC_CH);
    servo_current_pulse_us = pulse_us;
}

static void servo_stop_ppm()
{
    // Duty 0 = constant LOW = no servo pulses → the self-holding actuator de-powers.
    ledc_set_duty(SERVO_LEDC_SPEED, SERVO_LEDC_CH, 0);
    ledc_update_duty(SERVO_LEDC_SPEED, SERVO_LEDC_CH);
}

// ─────────────────────────────────────────────────────────────────────────────
//  Public API
// ─────────────────────────────────────────────────────────────────────────────

void servo_output_init()
{
    ledc_timer_config_t timer_cfg = {
        .speed_mode      = SERVO_LEDC_SPEED,
        .duty_resolution = LEDC_TIMER_14_BIT,
        .timer_num       = SERVO_LEDC_TIMER,
        .freq_hz         = (uint32_t)SERVO_LEDC_FREQ_HZ,
        .clk_cfg         = LEDC_AUTO_CLK,
    };
    esp_err_t err = ledc_timer_config(&timer_cfg);
    if (err != ESP_OK) {
        DBG_PRINTF("[SERVO] ledc_timer_config failed: %d\n", err);
        return;
    }

    // Start at the configured height so the servo doesn't sweep on boot.
    // mower_config_init() is guaranteed to run before servo_output_init().
    uint16_t init_pulse_us = heightToServoPulse(
        (float)mower_config_get().cut_height_max_mm);

    ledc_channel_config_t ch_cfg = {
        .gpio_num   = SERVO_PIN,
        .speed_mode = SERVO_LEDC_SPEED,
        .channel    = SERVO_LEDC_CH,
        .intr_type  = LEDC_INTR_DISABLE,
        .timer_sel  = SERVO_LEDC_TIMER,
        .duty       = pulseUsToDuty(init_pulse_us),
        .hpoint     = 0,
        .flags      = { .output_invert = 0 },
    };
    err = ledc_channel_config(&ch_cfg);
    if (err != ESP_OK) {
        DBG_PRINTF("[SERVO] ledc_channel_config failed: %d\n", err);
        return;
    }
    servo_current_pulse_us = init_pulse_us;
    s_servo_last_drive_ms = millis();
    s_servo_idle          = false;

    DBG_PRINTF("[SERVO] Ready — GPIO%d, %dHz, 14-bit, range %d–%d µs\n",
                  SERVO_PIN, SERVO_LEDC_FREQ_HZ, SERVO_MIN_US, SERVO_MAX_US);
}

// ─────────────────────────────────────────────────────────────────────────────

uint16_t heightToServoPulse(float height_mm)
{
    float t = (height_mm - (float)CUT_HEIGHT_MIN_MM)
              / (float)(CUT_HEIGHT_MAX_MM - CUT_HEIGHT_MIN_MM);
    t = 1.0f - clampf(t, 0.0f, 1.0f);  // invert: lower height = longer pulse
    return (uint16_t)((float)SERVO_MIN_US + t * (float)(SERVO_MAX_US - SERVO_MIN_US));
}

// ─────────────────────────────────────────────────────────────────────────────

void servo_set_height_mm(float height_mm)
{
    float clamped  = clampf(height_mm, (float)CUT_HEIGHT_MIN_MM, (float)CUT_HEIGHT_MAX_MM);
    uint16_t target_us = heightToServoPulse(clamped);

    // ── Persistent slew state ─────────────────────────────────────────────────
    static uint16_t s_slew_us     = 0;
    static uint16_t s_prev_target = 0;
    static bool     s_backoff     = false;

    if (s_slew_us == 0) {
        s_slew_us     = servo_current_pulse_us;
        s_prev_target = servo_current_pulse_us;
    }

    if (target_us != s_prev_target) {
        if (target_us > s_prev_target) s_backoff = false;
        s_prev_target = target_us;
    }

    // ── Slew step ─────────────────────────────────────────────────────────────
    int32_t step = (int32_t)target_us - (int32_t)s_slew_us;
    bool raising  = (step < 0);
    if (step >  (int32_t)SERVO_SLEW_US_PER_TICK) step =  (int32_t)SERVO_SLEW_US_PER_TICK;
    if (step < -(int32_t)SERVO_SLEW_US_PER_TICK) step = -(int32_t)SERVO_SLEW_US_PER_TICK;
    s_slew_us = (uint16_t)((int32_t)s_slew_us + step);

    if (raising && s_slew_us == target_us) s_backoff = true;

    // ── Backoff at raised end ─────────────────────────────────────────────────
    // Relieves mechanical strain when holding at maximum height.
    uint16_t output_us = s_slew_us;
    if (s_backoff) {
        uint32_t backed = (uint32_t)s_slew_us
                        + (uint32_t)((SERVO_MAX_US - SERVO_MIN_US) * SERVO_BACKOFF_PCT / 100);
        if (backed > SERVO_ABS_MAX_US) backed = SERVO_ABS_MAX_US;
        output_us = (uint16_t)backed;
    }

    // Only (re)drive on an actual movement; ledcWritePulse re-applies the duty, so
    // this also resumes the PPM if it had timed out. When the output is steady, the
    // timeout in servo_output_update() de-powers the actuator to stop it drawing
    // current fighting mechanical stiffness.
    if (output_us != servo_current_pulse_us) {
        ledcWritePulse(output_us);
        s_servo_last_drive_ms = millis();
        s_servo_idle          = false;
    }
}

// ─────────────────────────────────────────────────────────────────────────────
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

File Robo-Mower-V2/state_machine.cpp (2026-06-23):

// ══════════════════════════════════════════════════════════════════════════════
//  state_machine.cpp — RoboMower Top-Level State Machine
//
//  Implements all 11 robot states, LED patterns (FastLED), serial commands,
//  2 Hz JSON telemetry, and manual RC drive mapping.
//
//  Call state_machine_init() from setup(), then call state_machine_update()
//  from a FreeRTOS task at 10 Hz on Core 1.
//
//  References:
//    Spec:         Robo_Mower_claudecode_prompt_v3.md §"State Machine"
//    Assumptions:  ASSUMPTIONS.md A07, A08, A10, A23
//    Architecture: ARCHITECTURE.md §1
//    Config:       Robo-Mower-V2/config.h
// ══════════════════════════════════════════════════════════════════════════════

#include "state_machine.h"
#include "ble_server.h"

#include <FastLED.h>
#include <Preferences.h>

#include "config.h"
#include "mower_config.h"
#include "crsf_input.h"
#include "vesc_can.h"
#include "servo_output.h"
#include "ekf_localiser.h"
#include "rtk_gps.h"
#include "imu.h"
#include "perimeter.h"
#include "geometry.h"
#include "coverage_planner.h"
#include "obstacle_islands.h"
#include "node_follower.h"
#include "clipper_offset.h"
#include "odo_calib.h"
#include "cutting_monitor.h"
#include "bog_recovery.h"
#include "retrace.h"
#include "blade_recovery.h"   // Feature 2: RPM-load recovery (hosts STATE_RETRACE)
#include "safety.h"
#include "obstacle_map.h"
#include "battery_monitor.h"
#include "nvs_storage.h"
#include "collision_detect.h"
#include "heading_controller.h"
#include "crsf_telemetry.h"
#include "wheel_duty_ramp.h"
#include "sys_log.h"

// ── Colour constants (0xRRGGBB) ──────────────────────────────────────────────
#define COL_BLUE    0x0000FF
#define COL_GREEN   0x00FF00
#define COL_AMBER   0xFF8C00
#define COL_YELLOW  0xFFFF00
#define COL_ORANGE  0xFF4500
#define COL_RED     0xFF0000
#define COL_CYAN    0x00FFFF
#define COL_WHITE   0xFFFFFF
#define COL_PURPLE  0x800080

// ── FastLED arrays ────────────────────────────────────────────────────────────
// Shared array: index 0 = onboard LED, indices 1..LED_EXTERNAL_COUNT = strip
static CRGB s_leds[1 + LED_EXTERNAL_COUNT];

// ── Forward declarations ──────────────────────────────────────────────────────
static bool mower_inside_perimeter();
static bool auto_entry_allowed(const GpsMeasurement &gps);     // all AUTO-start gates
static const char *auto_entry_block_reason(const GpsMeasurement &gps);  // nullptr = OK
static void deny_auto_entry(const char *who);

// ── Module-level state ────────────────────────────────────────────────────────
static volatile RobotState g_state = STATE_INIT;
static bool     g_state_entry = true;   // true on first tick of a new state
static RobotState g_prev_state = STATE_INIT;  // state before last transition

// Pending state transition target (applied at end of tick)
static RobotState g_next_state = STATE_INIT;
static bool       g_transition_pending = false;

// Event-triggered pause latch: set when a safety event (perimeter breach,
// blade fault) drives the mower into STATE_PAUSED.  The operator must cycle
// the pause switch (activate then deactivate) to acknowledge before the mower
// will accept a resume command.  Operator-initiated pauses leave this clear.
static bool s_pause_event_latch = false;

// Serial line buffer
static char  s_serial_buf[128];
static uint8_t s_serial_len = 0;

// 2 Hz telemetry timer
static uint32_t s_telem_last_ms = 0;

// Battery update divider (10 Hz tick / 5 = 2 Hz)
static uint8_t s_bat_div = 0;

// ── BLE module state ──────────────────────────────────────────────────────────
#define BLE_CMD_MAX_LEN 1024
struct BleCmdSlot { char json[BLE_CMD_MAX_LEN]; };
static QueueHandle_t s_ble_cmd_queue = nullptr;
static bool s_last_armed = false;    // updated each tick; read by is_armed getter
static bool s_prev_armed = false;   // edge detection for armed beep
static uint8_t s_prev_ch4_mode = 0xFF; // edge detection for mode-switch beep (0=manual,1=auto,2=return); 0xFF = uninitialised

volatile bool g_ble_map_pending    = false;
volatile bool g_ble_status_pending = false;
volatile bool g_ble_diag_pending   = false;

// ── AUTO_MOWING state locals ──────────────────────────────────────────────────
static float    s_desired_cut_height_mm = 200.0f;  // overwritten in state_machine_init() from config
static uint32_t s_cross_track_exceed_ms = 0;  // millis() when |XTE| first > 0.5 m
static bool     s_blade_commanded = false;
static float    s_blade_ramp_erpm  = 0.0f;    // target eRPM sent to blade VESC (0 or full target)
// (blade battery lockout removed 2026-06-12 — VESC firmware handles low-voltage
//  power reduction internally; battery LOW is notification-only)
static uint32_t s_session_start_ms = 0;       // millis() when AUTO_MOWING was entered

// ── BLE drive overlay (RC failsafe only) ─────────────────────────────────────
// WebUI drive only activates when the RC TX is off (failsafe active).
// Timeout must be long enough for a slider held at a fixed position — the
// WebUI only sends SET_DRIVE on movement events, not continuously.
#define BLE_DRIVE_TIMEOUT_MS  5000  // 5 s grace after last active control input
static float    s_ble_throttle   = 0.0f;   // [-1, +1] from SET_DRIVE command
static float    s_ble_steering   = 0.0f;   // [-1, +1] from SET_DRIVE command
static uint32_t s_ble_drive_ms   = 0;       // millis() of last SET_DRIVE received
static bool     s_ble_pause      = false;   // BLE pause state (OR'd with CH7 + GPIO)
static bool     s_ble_arm        = false;   // BLE arm/blade state
static bool     s_ble_learn      = false;   // BLE learn mode toggle

// ── "Looking around" animation (IDLE, no perimeter configured) ───────────────
// Drives left ~90°, then right ~180°, then back to centre — a visible prompt
// that the mower has no perimeter and needs to be taught one.
// Runs once per power-on session, not on every IDLE entry.
enum LookPhase : uint8_t {
    LOOK_NOT_STARTED = 0,
    LOOK_LEFT,
    LOOK_PAUSE_1,
    LOOK_RIGHT,
    LOOK_PAUSE_2,
    LOOK_CENTRE,
    LOOK_DONE
};
static LookPhase s_look_phase = LOOK_NOT_STARTED;
static uint32_t  s_look_ms    = 0;
// Duty for animation turns — gentle, not fast.
#define LOOK_DUTY        0.20f
// Time at LOOK_DUTY for approximately 90° of rotation (tune to your chassis).
#define LOOK_TIME_90_MS  2500U
#define LOOK_PAUSE_MS     400U

// ── PAUSED / MOTORS_OFFLINE state locals ──────────────────────────────────────
// Pause is level-based: mower is paused whenever CH7, GPIO switch, or BLE pause is active.
// No edge detection needed — all inputs are treated as latching switches.
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

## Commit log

2026-06-13 Initial commit: RoboMower autonomous RTK GPS mower
    ESP32-S3 firmware (Robo-Mower-V2 sketch), single-file Web Bluetooth PWA,
    and the TX16S EdgeTX telemetry widget, plus manual.md / telemetry.md docs
    and the host-build geometry test harness.
2026-06-13 Add files via upload
    This is an adaptor you can print to mount an E-Stop button (purchased here: https://www.amazon.co.uk/dp/B0892976RR) to your TX16S RC Transmitter.
    [E-Stop Tx.STEP]
2026-06-14 WIP: Clipper2 spiral coverage planner, GPS heading-lock, blade-load fix (does not work yet)
    Coverage: replace boustrophedon strip planner with a concentric inward spiral built on vendored Clipper2 (src/clipper2/, Boost). Offsets from the perimeter keeping all sub-regions (covers pinched-off side arms), depth-first with short bridges between rings + centroid plunge to the centre. Perimeter is treated as the steering-centre limit (ring 0 = perimeter, uniform spacing). Hand-rolled insetPolygon kept for unit tests only; clipper_offset.h/.cpp wrapper.
    Heading: lock EKF heading to GPS travel direction on straight, measurable segments (strong gain), IMU between; buffers slow-creep travel. Fixes th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
    [Robo-Mower-V2.ino, ble_server.cpp, bog_recovery.cpp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]
2026-06-14 Fix stale code comments and condense CLAUDE.md to match current firmware
    - .ino header: CAN 250 kbit/s (not 500), TWAI TX/RX pins (GPIO2=TX,
    GPIO1=RX), battery telemetry source = blade VESC ID 3 (not drive ID 1)
    - Sweep ~50 stale comments across 28 source files: boustrophedon->spiral
    planner, pure_pursuit->node_follower, battery source ID, SET_CURRENT
    packet ID 1, vesc_poll_tachometer sends no frame, EKF 10 Hz odometry
    (no ekf_update_odometry), GPS innovation gate 5 m, RTK = DFRobot lib
    (not LC29H NMEA), IMU addr 0x69, GpsOrigin 24 bytes, MOWER_STATUS 19 B,
    gated AUTO fault responses, RPM blade control, sys_log thread-safe,
    BLE binary fragments, servo init 1000 us, LED fast-fla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
    [Robo-Mower-V2.ino, ble_server.cpp, config.h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]
2026-06-14 Reconcile README with current firmware
    - Path planning described as a concentric inward spiral, not the old
    boustrophedon strips/infill
    - Note that the auto-recovery responses (bog-out, re-trace, obstacle
    routing) are currently disabled while detectors are re-tuned; blade is
    armed manually from the TX even in Auto
    - Wheel motors are commanded by duty cycle (not current control)
    - Flag collision detection as currently being re-tuned
2026-06-14 Add BNO055 IMU swap design spec
2026-06-14 BNO055 spec: remove IMUPLUS/odometry heading fallbacks; require recal/fix on heading loss
2026-06-14 Add BNO055 swap Plan 1 (driver foundation) implementation plan
2026-06-14 Add BNO055 swap Plan 3 (calibration UX) implementation plan
2026-06-14 config: BNO055 I2C/calib/axis-remap constants (replaces BMI270 0x69)
    [config.h]
2026-06-14 config: drop BMI270 from IMU I2C section heading comment
2026-06-14 imu: add device-neutral imu.h API (BNO055 contract)
2026-06-14 imu: BNO055 driver (NDOF, 100Hz task, NVS cal, collision feed)
    [imu_bno055.cpp]
2026-06-14 imu: document lock-free cross-core flags + recal stall; fix TILT_EMA_ALPHA rate comment
    [config.h, imu_bno055.cpp]
2026-06-14 imu: delete BMI270 driver, repoint includes to imu.h, imu_init()
2026-06-14 ble: diagnostics use BNO fused heading + calib (drop removed getters)
2026-06-14 imu: swap .ino IMU library include SparkFun BMI270 -> Adafruit BNO055
    [Robo-Mower-V2.ino]
2026-06-14 config: replace gyro-pivot/bootstrap/GPS-lock with offset-trim constants
    [config.h]
2026-06-14 ekf: header — drop gyro arg from ekf_predict, add offset getter/persister
2026-06-14 ekf: BNO-primary heading + GPS offset trim; delete odometry/gyro/lock heading
2026-06-14 sm: ekf_predict without gyro; persist heading offset each EKF tick
2026-06-14 sm: AUTO heading-confidence gate replaces 2m-clearance + creep bootstrap
    [state_machine.cpp]
2026-06-14 telemetry: add BNO calibration byte to MOWER_STATUS (0x80, now 20 B)
2026-06-14 ble: STATUS JSON adds imuCalSys/imuCalMag/headingConfident
2026-06-14 sm: RECAL_IMU BLE command triggers imu_recalibrate()
2026-06-14 pwa: mag-cal banner + Recalibrate compass button (RECAL_IMU)
2026-06-14 collision: BNO linear-accel source, fresh NVS baseline, expose jolt RMS
    [collision_detect.cpp]
2026-06-14 config: collision RMS window 25 samples (250ms at the 100Hz BNO rate)
    [config.h]
2026-06-14 sm: log collision baseline + jolt RMS every 5s while driving (capture)
    [state_machine.cpp]
2026-06-14 docs(readme): heading paragraph - state magnetometer heading, drop prior gyro/odometry comparison
2026-06-15 imu(bno055): negate pitch/roll to match imu.h convention (bench-confirmed 2026-06-15)
2026-06-15 imu: heading-confidence + profile-save gate on mag/gyro/accel, drop unreliable BNO sys; match Lua banner
2026-06-15 sm: remove MANUAL->IDLE auto-revert when stationary + IDLE deck-to-max
    Operator-requested. The 2s-throttle-centred MANUAL->IDLE revert dropped the
    machine out of MANUAL whenever it stopped, so the cut-height servo stopped
    tracking CH3 and the blade could not be armed while stationary. The IDLE entry
    also forced the deck to max height (unwanted, unexpected movement). Both removed;
    MANUAL now stays MANUAL until the operator changes mode (real RC failsafe with TX
    off still stops, unchanged). No behaviour added.
    [state_machine.cpp]
2026-06-15 imu: save BNO calibration via direct register read (bypass getSensorOffsets sys==3 gate)
2026-06-15 imu/ui: rely on BNO055 auto-calibration - stop gating AUTO on cal status; remove MAG CAL banners (Tx + PWA); add optional Calibrate compass button (RECAL_IMU) in PWA Diagnostics
2026-06-15 ekf: revert speculative bno-based reverse-correction (drive sign verified correct); add temporary HDG diagnostic log (bno/theta/offset) to localise the AUTO heading-flip
    [state_machine.cpp]
2026-06-16 Implement four-item roadmap: PWA settings save, learn-point latency, perimeter lat/lon storage, BNO055 cal persistence
    Items implemented in dependency order (see docs/superpowers/.. plan and docs/TODO.md
    for per-item verification steps; all compile, host test passes, PWA JS valid).
    1. PWA "Save/Load settings to file" (config only) — robomower.html: export 38
    MowerConfig fields by name to JSON; import fills missing keys from CFG_DEFAULTS
    (mirrors config.h), ignores unknown keys. No firmware change.
    2. Learn-point latency — CH8 press is edge-latched in crsf_input at the ~200 Hz
    CRSF rate into a counter the 10 Hz FSM drains, so brief taps are never dropped.
    3. GPS/Map mismatch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
    [crsf_input.cpp, imu_bno055.cpp]
2026-06-16 feat: WGS-84 absolute coordinates (Feature 1) + RPM-based blade load & recovery (Feature 2)
    Feature 1 - coordinates end-to-end (SJRToDo #1):
    - rtk_gps: replace fixed 111319.5 flat-earth constant with a WGS-84 local
    tangent plane (geodetic_scales: ellipsoidal M/N radii at origin latitude).
    - BLE protocol v2: absolute lat/lon (+per-point accuracy) on the wire; firmware
    owns the ENU origin. SEND_PERIMETER parses [[lat,lon,acc],...]; MAP emits
    lat/lon for perimeter/nav/work/paths/pos. Pre-v2 ENU uploads rejected.
    - perimeter: store exact lat/lon + per-point accuracy (perimeter_store_canonical_latlon),
    stream via perimeter_canonical_count/_point (no duplicate buffer).
    - PWA: pure lat/lon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
    [blade_recovery.cpp, ble_server.cpp, config.h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]
2026-06-18 fix: live map position + RTK accuracy + IMU cal capture/backup; PWA dated files; defaults refresh
    Live map position (TELEM lat/lon):
    - ble_server: TELEM now carries the EKF steering-centre as absolute lat/lon
    (posLat/posLon, firmware-projected). PWA plots it directly so the arrow tracks
    at the telemetry rate with no origin re-projection (fixes the ~2 m offset and
    the arrow only moving on a manual "load from mower"). ENU fallback kept.
    Live RTK accuracy for the perimeter:
    - rtk_gps_accuracy_m(fix,hdop) = base × max(hdop,1) × √2 (matches the EKF/display).
    perimeter_record_point now takes the live acc_m instead of fix_type; the coarse
    accuracy_for_fix table (fixed 0.50 m for RTK-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
    [ble_server.cpp, config.h, imu_bno055.cpp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]
2026-06-18 docs: drop misleading "magnetic interference" attributions from IMU/heading comments
    The chassis is stainless + aluminium (only the blade is ferrous) and the ambient
    field at the sensor is clean (verified with a phone magnetometer), so comments
    that blamed magnetometer/motor/blade interference were both wrong and a recurring
    red herring that steered debugging away from the actual (code) causes.
    - config.h: drop "mag decays when held still" from the calib-gate note.
    - ekf_localiser.cpp: "if the BNO heading itself flips (e.g. magnetic distortion)"
    -> "if the BNO heading itself is wrong (for any reason)".
    - imu_bno055.cpp: "A magnetically-noisy machine never reaches sys==3" -> the BNO055
    o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
    [config.h, imu_bno055.cpp, state_machine.cpp]
2026-06-18 fix: BLE log-freeze (fragment reassembly), Diagnostics cleanup, apply/load IMU calibration
    PWA system-log freeze (the real cause):
    - _reassemble() only reset the per-characteristic fragment buffer on a successful
    completion, so a single dropped BLE fragment (notify-queue overflow under load —
    the STATUS characteristic also carries diag) poisoned the buffer permanently and
    every later STATUS failed to reassemble, freezing the log at the first fetch.
    Now a fragment with index 0 (start of a new message) resets the buffer, so a drop
    can't freeze subsequent messages.
    - Move the system log off the Dashboard to the Diagnostics tab next to its Refresh
    button (Copy moved there too); Ref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
    [imu_bno055.cpp, state_machine.cpp]
2026-06-20 AUTO robustness: Fixed-only EKF/odo, reverse nav, nudge mode, smart pause/resume
    EKF: snap position & trim heading ONLY on RTK-Fixed; dead-reckon on Float (which can be ~2m off under tree cover). Cold-start seeds Fixed-pref (fallback kept). Breach watchdog's raw-GPS term gated to Fixed so Float wobble can't false-stop AUTO. odo_calib is consequently Fixed-only (its heading-event source is now Fixed-gated).
    node_follower: drive REVERSE to behind-targets (>90 deg) instead of wide forward arcs that cross the perimeter. Bridges become ~45deg-pivot + reverse + ~45deg-pivot + forward; behind start-points are reached by straight reverse. Hysteresis around 90deg; reverse capped at mowing speed.
    st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
    [ble_server.cpp, config.h, coverage_planner.cpp]
2026-06-20 docs(README,manual): spiral planner, RTK-Fixed-only positioning, NUDGE mode (was RETURN), reverse-to-behind nav, smart pause/resume, per-corner accuracy, red/black map arrows; battery notify-only + b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
2026-06-20 follower: counter-based reverse lock (1 back, 4 forward) + same-speed reverse; SM: 4s AUTO->MANUAL->AUTO resume grace
    Reverse to a behind-node could get stuck (the next node was then behind too). Replace the geometry lookahead with a counter: allow ONE backward node, then force REVERSE_FWD_LOCK_WAYPOINTS (4) forward before reverse is available again - geometry-independent, can never lock in reverse. Reverse now uses the same speed profile as forward (dropped the creep cap). State machine: an accidental AUTO->MANUAL flick resumes the cycle where it left off if AUTO is re-selected within AUTO_RESUME_GRACE_MS (4s); after that it's a fresh start. Initial field test good.
    Files: node_follower.cp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
    [config.h, node_follower.cpp, state_machine.cpp]
2026-06-22 obstacle_discs: source-tagged RAM disc list + bracket-based detour planner (host-tested)
2026-06-22 obstacle_discs: offset detour vias from disc centre + validate bracket legs (review fix)
2026-06-22 sm: reactive obstacle detour in AUTO (steer to via-points around discs; exhausted -> PAUSE)
2026-06-22 sm: detour review fixes - suppress XTE skip while detouring; zero blade VESC on detour-PAUSE
    [state_machine.cpp]
2026-06-22 pwa: Diagnostics buttons to inject/clear a test obstacle disc (detour mechanism test)
2026-06-22 config: COLLISION_RESPONSE_ENABLED (per-detector enable, default on)
    [config.h]
2026-06-22 sm: collision -> obstacle disc + brief back-up in AUTO; detour routes around (Plan 3)
    [state_machine.cpp]
2026-06-22 sm: collision review fixes - clear jolt flag after back-up; uniform back-up dist (side hits cleared disc)
    [state_machine.cpp]
2026-06-22 follower: expose node_follower_is_reversing() for the stall/slip intent gate
    [node_follower.cpp]
2026-06-22 config: STALL_RESPONSE_ENABLED, TILT_RESPONSE_ENABLED(0)+confirm/cap (Plan 4)
    [config.h]
2026-06-22 sm: stall -> PAUSE (intent-gated) + tilt reverse-to-clear behind TILT_RESPONSE_ENABLED (Plan 4)
    [state_machine.cpp]
2026-06-22 sm: skip detour planning during a recovery reverse (fixes collision/tilt PAUSE-instead-of-backup; mower starts inside its own fresh disc)
    [state_machine.cpp]
2026-06-22 sm: reset stall flag at recovery-reverse exits (no false PAUSE after back-up); tilt-reverse no-progress timeout cap
    [config.h, state_machine.cpp]
2026-06-22 config: SLIP_* constants (slip watchdog, default off) (Plan 5)
    [config.h]
2026-06-22 sm: slip watchdog (raw-GPS net-displacement) -> reverse -> disc/PAUSE, default off (Plan 5)
    [state_machine.cpp]
2026-06-22 sm: slip recovery yields to an active collision back-up (review hardening, Plan 5)
    [state_machine.cpp]
2026-06-22 config: BLADE_LOAD_* (speed-modulate on, reverse-retry off) (Plan 6)
    [config.h]
2026-06-22 sm: blade-load speed modulation + reverse-retry (4th recovery-reverse), default off (Plan 6)
    [state_machine.cpp]
2026-06-22 sm: blade-load review hardening - reset last-pose on entry; gate reverse-retry against other recoveries (Plan 6)
    [state_machine.cpp]
2026-06-23 lua: RTK FIXED badge black-on-white (sun-readable); drop the stuck +/-10mm ACC line
    [main.lua]
2026-06-23 feat: obstacle 'island' rename + PWA-switchable detector layers + cut-height actuator timeout + PWA UI
    - Rename obstacle disc->island throughout (module obstacle_islands.*, API, BLE cmds, PWA, host test).
    - AUTO exception-handling detectors runtime-switchable from PWA Settings (MowerConfig resp_* flags; NVS mow_cfg_v16).
    - Cut-height actuator PPM timeout (cut_height_timeout_s, default 3s, 0=continuous) to stop the 5A hold current.
    - PWA: 6 tabs (Settings + Log split out), full-height newest-first log, single BLADE pill, 1mm cut-height slider.
2026-06-27 docs: add Libraries & Dependencies (pinned versions, incl. DFRobot RTK lib) to README; document the ESP32-core BLE build error + fix
2026-06-27 ble: build on esp32 core 3.0.5 through 3.3.x (NimBLE)
    Newer cores move the ESP32-S3 onto the NimBLE BLE stack, where
    esp_ble_gatts_cb_param_t doesn't exist - so the old
    onConnect(BLEServer*, esp_ble_gatts_cb_param_t*) override failed to
    compile ('has not been declared'). Switch to the unconditional
    parameter-less onConnect(BLEServer*) overload, which is declared and
    invoked on every core version and both backends (Bluedroid + NimBLE).
    The param was only used to set s_conn_id, which is never read, so drop
    both - no behaviour change. No version guards needed.
    Verified: compiles clean on 3.0.5 (46% flash, = baseline) and 3.3.9
    (28% flash). README dependency note updated: 3.0.5-3.3.x all build.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
    [ble_server.cpp]
